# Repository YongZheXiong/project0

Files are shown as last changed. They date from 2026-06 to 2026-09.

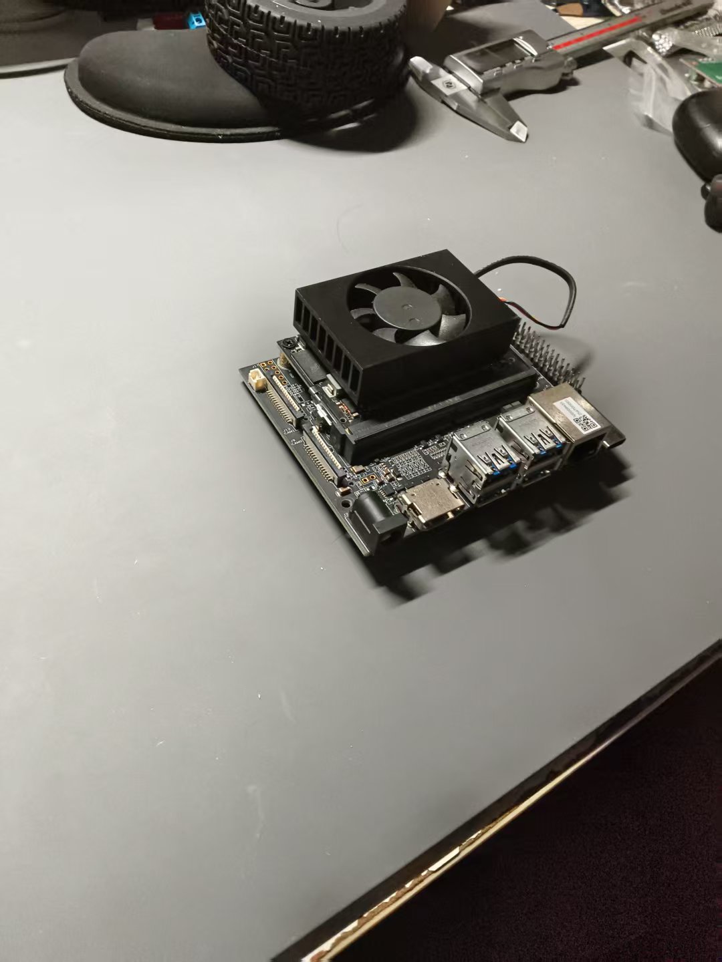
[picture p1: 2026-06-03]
hardware/reference_images/compute/EXIST-001_jetson_orin_nx_top_oblique.jpg

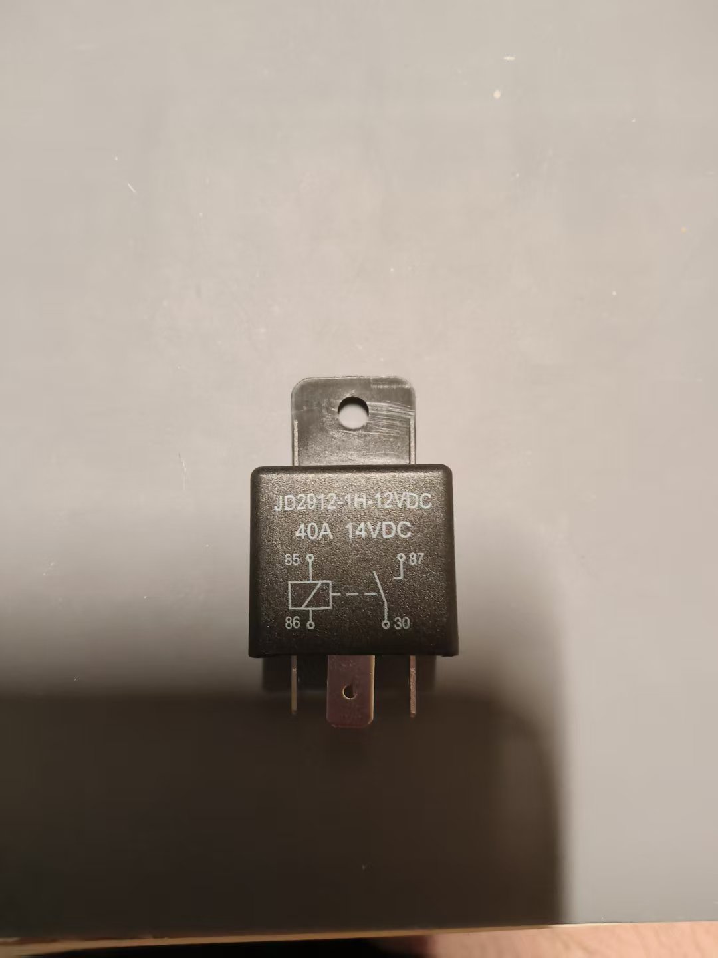
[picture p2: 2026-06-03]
hardware/reference_images/power/PWR-MOT-003_jd2912_relay_label_front_01.jpg

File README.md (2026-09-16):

# Project0

Project0 是一个面向室内走廊场景的四轮差速移动机器人项目，由个人完成机械、电气、底层控制、ROS2 软件与系统验收。项目以真机为主线，目标是形成可验证的感知—决策—执行闭环，依次完成基础运动、定位建图、导航和最小语义任务，并以完整项目报告收束成果。

## 项目目标

- 在固定室内走廊中建立可复现的单车系统基线。
- 让底盘、传感器、计算平台和 ROS2 软件形成真实闭环。
- 以分阶段验收记录机械、电气、通信、控制、感知和导航结果。
- 保留代码、配置、CAD、接线、测试与失败证据，支持复现和复盘。

## 当前进展

截至 2026-09-16，项目处于 H60 + MC520 底盘重建阶段。原 Orin NX/C1902 在一次电气异常后停止使用并送交专业维修；后续最终上位机可能为 Orin NX，也可能为 Orin Nano，型号尚未冻结。等待期间项目已推进 H60 能独立承接的四轮架空运动与断链安全子轨。

| 项目 | 当前状态 |
| --- | --- |
| 阶段与版本 | P2 / `v1.1-dev` / Unreleased；`v1.1.2` 已发布，冻结 H60-only 四轮架空与断链安全成果，P2 本身尚未完成 |
| 阶段门 | H0 已通过；H1/H2/H3/H5/H6 为 PARTIAL，H4 NOT RUN，H7 NOT PASSED，H8 NOT RUN；H1/H2 最终配置验收等待最终上位机到位 |
| 机械 | 28 个当前整车 STEP 已完成数字复审；H60 最终固定、线束应力释放与轮周净空已有用户报告受限证据，最终质量/重心、维护/风道和传感器视场回归等待最终上位机配置 |
| 固件 | 已同步 H60 默认安全固件、调度/诊断隔离、单通道表征、四轮固定 profile 和失联短租约回归；默认构建仍为 `MOTION=0 / CAL=0` |
| ROS2 | 已同步 H60 二进制协议桥、校准保持命令编码、手柄输入与安全仲裁的离线基线；Orin 不可用期间不声称完成 ROS2/实机联调 |
| 阶段性成果 | W2/M3 已取得 H60-only 受限通过：最终四路线束架空前进/后退/STOP，以及真实 USB-COM 断开后的定性四轮停车；不等于完整 H7/H8 |
| 历史平台 | STM32 + WSDC2412D + JGB37-520 + 三层底盘资料已归档 |

数字复审确认当前 CAD 的 28 个 STEP 均为有效 B-Rep，轴距为 `170 mm`、轮距约 `184.16 mm`，采用 6 根层间支柱，D435 水平安装。加工件到货后仍需按 H1 完成尺寸、孔位、平面度、连接器、风道、线束与维护空间的实物复核。

## 系统组成

| 子系统 | 当前方案 |
| --- | --- |
| 主计算 | Jetson Orin NX 或 Orin Nano，待最终确定；原 Orin NX/C1902 维修隔离 |
| 底层控制 | OpenCTR H60 V3.7 |
| 底盘 | 四轮差速，4 × MC520P56_12V，1:56，65 mm 橡胶轮 |
| 感知 | Livox Mid360 + Intel RealSense D435 |
| 供电 | 3S 电池 → 25A 主保险 → 主开关 → H60、Orin、Mid360 三条独立受保护支路 |
| 电压采样 | H60 `PC0` VIN ADC，多点校准后使用 |
| 通信目标 | Orin ↔ H60 版本化 UART 协议，带会话、序号、状态与故障语义 |

## 开发与验收

当前仓库提供 H60 架构、接线、默认运动锁定固件、受显式构建门保护的运动/诊断候选、二进制协议桥、CAD 和 H0-H8 验收基线。`v1.1.1` 冻结四轮单轮受限表征；`v1.1.2` 进一步公开 H60-only 四轮架空、断链停车和 localhost 安全控制核心。经完整 H5-H7 验收的动力运行固件仍在开发中。

Orin 维修期间的 H60-only 子轨不改变最终架构。既定手柄链是 USB 接收器接入 Orin 后经 ROS2/UART 下发；H60 是否能直接承接手柄输入仍为 `TBD / NOT RUN`，不会因临时目标调整而被写成已实现。

物理验证按以下顺序推进：

1. H0 到货与版本核对；
2. H1 不上电机械试装；
3. H2 断电电气检查；
4. H3 分支低能量上电；
5. H4 UART 单侧掉电与反向供电验证；
6. H5 固件故障注入；
7. H6 单通道电机与编码器；
8. H7 四轮架空与电源动态；
9. H8 受控场地落地低速。

当前停车与失能链由上电默认 `DISARMED`、显式 ARM、STOP/DISARM、通信超时、IWDG、异常撤 PWM、人工持续监护和主开关整车断电组成。车辆没有独立急停按钮、继电器或急停 GPIO；H8 仅在 H0-H7 全部通过、场地隔离、低速低加速度、主开关直接可达且操作者持续目视时执行。永久 UART 线束还需先完成任一侧掉电时的反向供电测量。

## 文档与资产入口

- [当前 H60 + MC520 实现基线](docs/02_architecture/p2_h60_rebuild_baseline.md)
- [无 Orin 本机网页控制覆盖层](docs/02_architecture/no_orin_web_teleop_architecture.md)
- [系统架构](docs/02_architecture/system_architecture.md)
- [电源、运动与采样边界](docs/02_architecture/h60_power_motion_sampling_boundary.md)
- [H60 电源接线](hardware/wiring/h60_power_wiring_v0_2.md)
- [H60 运动控制固件要求](firmware/h60_motion_control_firmware_requirements_v0_2.md)
- [H0-H8 重建验收计划](docs/06_testing/p2_h60_mc520_rebuild_acceptance_plan_2026-08-16.md)
- [当前公开 BOM](hardware/bom.md)
- [当前整车 CAD](hardware/cad/current_vehicle_v0_2/README.md)
- [重建基线报告](reports/h60_mc520_rebuild_baseline_2026-08-16.md)
- [v1.1.1 四轮单轮表征报告](reports/h60_four_wheel_characterization_v1_1_1.md)
- [v1.1.2 H60-only 四轮架空与断链报告](reports/h60_no_orin_w2_m3_v1_1_2.md)
- [无 Orin 本机安全控制台](tools/no_orin_web_teleop/README.md)
- [版本记录](CHANGELOG.md)
- [完整发布说明](docs/releases/README.md)

## 仓库结构

```text
Project0_public/
├── config/       # 配置入口
├── data/         # 数据索引与样例
├── docs/         # 架构、部署、标定与测试文档
├── firmware/     # H60 固件要求与上一平台实测记录
├── hardware/     # BOM、CAD、接线、参考资料与历史归档
├── reports/      # 系统与测试报告
├── scripts/      # 可复跑检查和测试工具
├── simulation/   # 仿真入口
├── src/          # ROS2 软件入口
├── tools/        # 离线控制、仿真与验证工具
└── presentation/ # 展示材料入口
```

## 历史资料

上一 STM32/JGB/WSDC 平台的 CAD、照片、接线和硬件台账保存在 `hardware/archive/`。历史文件中的完成状态仅对应其记录日期和当时平台；当前 H60 + MC520 新车以本 README、H60 架构文档和 H0-H8 验收计划为准。

## 版本、许可证与作者

- 当前开发版本：`v1.1-dev`；最新阶段性成果版本为 `v1.1.2`，下一候选为 `v1.1.3`。P2 完成并通过发布审查后才进入正式 `v1.1`。
- 最新阶段性成果：`v1.1.2`（2026-09-16），冻结 H60-only 四轮架空前进/后退/STOP、真实 USB-COM 断开后的定性停车证据和 localhost 安全控制核心；不表示 P2 或落地运动验收完成。
- 前一阶段性成果：`v1.1.1`（2026-09-08），冻结四轮单轮运动方向、编码器符号、工程 CPR 与受限停车证据。
- 最新历史开发预发布：`v1.1-dev.2`（2026-09-01）；它冻结 H0 基线与 H60 安全控制检查点，不表示 P2、基础运动或手柄控制已完成。
- 版本索引：[CHANGELOG.md](CHANGELOG.md)；完整说明：[docs/releases/README.md](docs/releases/README.md)
- 许可证：当前 [LICENSE](LICENSE) 为待确定占位，复用或分发前请先确认后续正式许可。
- 作者：Yongzhe Xiong

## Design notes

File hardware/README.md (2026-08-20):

# Project0 硬件目录

> 当前边界：当前方案是 H60 V3.7 + 4×MC520 的两层单车系统；只有 H60 `PC0` VIN 电压采样，没有独立急停按钮、继电器、急停 GPIO 或车载电流采样。
> 现场状态：采购、到货、装车、接线、上电、刷写和运动状态以对应验收记录及本轮现场确认为准。

## 当前活动入口

| 路径 | 作用 |
| --- | --- |
| `bom.md` | 当前整车主件、状态与验证入口 |
| `cad/current_vehicle_v0_2/` | 当前唯一活动 CAD 库，共 28 个 STEP |
| `wiring/h60_power_wiring_v0_2.md` | 当前唯一接线设计入口；尚未实装 |
| `reference_docs/` | 当前硬件原厂文档入口；尚缺 H60 / MC520 可归档的官方手册 |

## 历史归档

`archive/` 统一保留上一辆 STM32/JGB/WSDC 小车的 CAD、线束、电源调试、图片与 P1.3 盘点文档；WSDC 数据手册未包含在当前公开快照。归档中的急停、继电器、ACS712、STM32、WSDC、六路保险盒和三层车体只是历史事实，不得作为当前采购、接线、固件或验收输入。

## 当前维护规则

1. 当前硬件边界变化必须先形成可追溯依据，再同步 BOM、CAD、接线与验收计划。
2. 只有实物和原始证据可以把状态从“待采购/待确认”改为“已到货/已实装/已验证”。
3. 当前线径、端子、支路保护定值与 UART 反灌防护仍须在 H2–H4 根据实物冻结。
4. 当前 CAD 已通过数字结构检查，但不替代实物尺寸、公差、试装、强度、散热、线束可达性和维护性验收。

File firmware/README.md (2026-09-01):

# Firmware Workspace

本目录承接 Project0 当前 H60 固件需求，以及上一 STM32 平台的固件和实测历史。

当前入口包括 `h60_safe_control/` 与 `h60_motion_control_firmware_requirements_v0_2.md`。`h60_safe_control` 已提供并验证 `v0.1.1` 运动锁定固件：默认 `DISARMED`、显式 ARM 拒绝、协议边界、通信超时、IWDG 和异常撤 PWM；生产构建固定 `MOTION=0`，不配置 PWM，也不放行接电机或运动。反转斜坡、闭环和动力验收仍待实现。

以下 STM32 记录均为上一实车平台历史，不适用于 H60 引脚、协议、电机方向、编码器 CPR 或新平台验收：

上一 STM32 平台已有记录：

| 文件 | 作用 | 状态 |
|---|---|---|
| `stm32_safe_init_v0_1.md` | 记录 P2 电驱控制端安全初始化工程、GPIO 分配、编译/调试路径和实测结果 | 已完成阶段记录 |
| `stm32_lf_single_motor_pulse_test_v0_1.md` | 记录左前 `LF` 单电机低占空比短脉冲测试的临时固件行为、诊断过程和测试结果 | 已完成阶段记录 |
| `stm32_four_single_motor_pulse_tests_v0_1.md` | 记录 `LF / LR / RF / RR` 四个单电机低占空比短脉冲测试、右侧实物映射、主输入保险故障处理和测试后安全回烧 | 已完成阶段记录 |
| `stm32_suspended_linkage_pulse_tests_v0_1.md` | 记录悬空同侧双电机联动、四轮联动、右侧方向补偿、`LF` 起转门槛诊断和测试后安全回烧 | 已完成阶段记录 |
| `stm32_uart3_minimal_test_v0_1.md` | 记录 USART3 `PB10/PB11` 最小 UART 测试固件、双向 ACK、烧录和重启 / 冷启动复验 | 已完成阶段记录 |
| `stm32_encoder_acceptance_v0_1.md` | 记录旧平台新映射安全输出、四路编码器手动转轮、交叉测试、`LF` 故障定位和替换后复验 | 四路编码器低功率手动转轮通过 |

历史记录注意：

1. 旧 STM32CubeIDE 工程保留在非公开本地工作区，未纳入公开仓库源码管理；公开文档只保留可复核的历史结果摘要；
2. 仓库内 `stm32_safe_init_v0_1.md` 只记录该工程的事实、关键代码行为和验证结果；
3. `stm32_lf_single_motor_pulse_test_v0_1.md` 只记录一次左前单电机临时测试；
4. `stm32_four_single_motor_pulse_tests_v0_1.md` 记录四个单电机测试均已通过；`stm32_suspended_linkage_pulse_tests_v0_1.md` 继续记录悬空同侧联动、四轮联动和方向补偿结果；
5. 2026-06-22 的旧平台方向重映射作为历史结果保留；完整针序未在当前公开快照展开，不得迁移到 H60；
6. 当前悬空方向一致性已通过，但仅在悬空、短时、人工看守条件下成立，不表示整车落地运动已完成；
7. 原 STM32 在故障发生前最后一次已知烧录为安全初始化固件，现已因 3.3V 和 `RESET / NRST` 异常保持隔离；替换板已完成供电、烧录和 USART3 双向验收；
8. 2026-06-16 已补记 USB / 调试器反供电现象：主开关 OFF 但 STM32 USB 插着时，电驱端曾约 `4.16V`；拔掉 USB 后为 `0V`，不应仅凭电驱灯判断主动力状态；
9. `stm32_uart3_minimal_test_v0_1.md` 只用于 Orin X / Orin NX 与 STM32 UART 物理链路验证，烧录前第 4 路动力保险应保持拔出；
10. 2026-06-20 已完成替换板 USART3 最小双向 ACK、Orin 重启和 Orin / STM32 控制支路断电冷启动复验；正式控制协议当时仍未完成；
11. `stm32_safe_init_v0_1.md` 和既有短脉冲测试记录基于旧右侧引脚，只作为历史事实；改线后禁止直接使用旧固件恢复动力；
12. 2026-06-22 新映射固件已完成编译、烧录、安全输出、UART 和编码器读取测试；`LR / RF / RR` 编码器通过，`LF` 经交叉测试定位为电机内置编码器 / 内部连接器 / 原厂尾线侧故障；
13. 2026-07-13，`LF` 替换电机装车后重新压紧编码器蓝线 / 黑线并复验通过，四路编码器在第 4 路动力保险空置、人工手动转轮、UART 读数条件下均可产生有效计数；
14. 2026-07-13，旧 Windows STM32 工程已通过 U 盘取回，新 Mac 可构建当前 `project0_stm32_uart3_test`，车上 flash 已只读备份，active 固件前缀与旧 Windows 工程产物、新 Mac 构建产物一致；
15. 2026-07-14，`project0_stm32_uart3_test` 已加入阶段 D 前置控制层：新增 `STOP / SAFE / PULSE / DRIVE` 文本命令、`300ms` 通信超时停车、非法命令停车、`250ms` 短脉冲上限、`20 / 55` compare 上限和急停 `NO` 反馈状态；当日烧录 ELF SHA-256 为 `eb4d9c21ad2c4331132bc7258b529735dcae35e5e25987500af1212eea817ca5`；
16. 2026-07-14，用户确认第 4 路动力保险拔出后，阶段 D 前置控制固件已通过 OpenOCD 烧录到车上替换 STM32 并 `Verified OK`；Orin `/dev/ttyTHS1` 默认低功率 UART 复验 `overall=PASS`，未发送 `PULSE / DRIVE` 主动运动命令；当前观测到 `ESTOP=1`，需在阶段 D 前人工确认急停按钮状态和 `NO` 反馈转换；
17. 2026-07-17，急停按下 / 释放的 `ESTOP=1/0` 转换、急停动力切断、四路悬空前进 / 后退短脉冲和自动停车通过；诊断期间发现左后 `LR` 不动作，交叉测试证明电机与编码器正常，最终定位为 `set_left_forward()` 遗漏 `PD2 / PD3`；
18. 左后方向输出修复后的 ELF SHA-256 为 `583880a87b278a84922d24435b415d90d7ea15c16e880d584ec80ce4fb99e596`，OpenOCD `Verified OK`；动力保险拔出时正向输入实测 `INA2=0.17V`、`INB2≈3.3V`，恢复动力后的 `FWD / REV 12/55 200ms` 动作和编码器方向通过；
19. 2026-07-17，悬空 `LEFT / RIGHT 12/55 200ms`、单次 `DRIVE` 无新指令 `300ms` 超时和通信客户端中断后独立停车通过；形成原始编码器符号表，后续里程计应保留左侧符号并对右侧计数取反；
20. 阶段 D 悬空低层运动与安全停车验收完成；测试后急停按下、整车断电并拔出第 4 路动力保险。该结果不等同于里程计、ROS2 teleop、人工接管仲裁或阶段 E 落地运动通过。

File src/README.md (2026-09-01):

# ROS2 Source Workspace

`src/` 是 Project0 的 ROS2 Humble 源码包入口。当前已提供 H60 迁移的离线实现：

> `p0_base_bridge` 活动节点现使用 H60 版本化二进制协议、原始字节串口、STOP、新会话心跳、输入回中、显式 ARM、A-D 遥测和 ACK/NACK；`p0_safety_manager` 使用 `motion_ready` 和软件运动锁。默认配置保持 `motion_commands_enabled=false`、`wheel_mapping_confirmed=false`、`wheel_target_limit_mmps=0`，H60 `v0.1.1` 还固定报告运动输出不可用，所以本代码不能申请 ARM。旧 STM32 文本解析、16-bit 解绕、CPR 和 `ESTOP` 字段仅作历史兼容，不参与活动路径。本轮仅有 Mac 离线测试，不表示 Orin ROS2 构建、UART 实机、H4/H5、接电机或运动通过。

| 包 | 职责 | 当前边界 |
| --- | --- | --- |
| `p0_interfaces` | 底盘指令、H60 状态和运动锁服务 | `ChassisStatus` 已新增协议/固件版本、状态机、VIN、故障和 A-D 原始计数；旧 LF/RF 与 ESTOP 字段保持中性兼容 |
| `p0_base_bridge` | ROS2 到 H60 `/dev/ttyTHS1` 的二进制桥 | 离线实现已完成；A-D 映射、方向、CPR、轮径、Orin ROS2/H60 实机和单侧掉电反供电仍未验证，默认双门关闭 |
| `p0_safety_manager` | 通信/运动就绪、软件运动锁、手动/自动命令仲裁 | `/p0/motion/stop` 与 `/p0/motion/clear_lock` 已取代活动运行路径中的旧软件急停服务；清锁不自动 ARM |
| `p0_manual_control` | Flydigi Linux joystick 动态发现、无线心跳与 `sensor_msgs/Joy` 手动指令适配 | 真实映射和关机断开清零已无动力复验 |
| `p0_bringup` | 安全默认的组合启动和参数 | `base_control_no_motion.launch.py` 默认不产生活动运动指令 |

本机可运行不依赖 ROS2 的协议、串口、会话门控和仲裁单元测试。旧 STM32 平台的通信、计数解绕与 RR 失计只作为历史兼容背景，不是当前 H60 P2 阻塞。

`package.xml` 中的 `0.1.0` 是各 ROS2 包自身的历史包版本，不是 Project0 项目发布版本，不参与 P0–P10 的 `v0.1`–`v2.4` 映射。

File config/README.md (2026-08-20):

# 全局配置入口

## 目录用途

`config/` 用于登记跨多个软件包共享、需要在运行时统一选择的配置。当前只有本 README 是有意的：P2 的 H60 配置尚未实现和验收，因此不能为了让目录“看起来完整”而复制一份未经验证的 YAML。

H60 动力运行 YAML 尚未实现和验收。上一 STM32/JGB 小车的配置用于旧软件复现，不作为当前默认值。

## H60 配置建立条件

H60 迁移时，应先在 ROS2 bringup 包内形成可安装的真实运行配置，并完成：

1. 协议版本、设备路径和 UART 周期；
2. STOP/DISARM、显式 ARM、命令超时和故障行为；
3. 四路方向、计数边沿、CPR、轮径、轮距和速度/加速度限制；
4. H60 PC0 VIN ADC 多点校准版本；
5. 无动力、架空和落地对应验收。

只有出现两个或以上软件包确实需要共享同一配置，或者需要稳定的仓库级配置选择入口时，才在本目录增加文件。不得把同一 YAML 同时复制到两个位置手工维护。

## 更新机制

- 配置值的改变必须来自真实实现、标定或测试，不从 README 自动生成。
- 每次更新同时记录来源、单位、硬件/固件版本、适用模式、验证状态和回滚值。
- P2 的关键参数选择、证据和验证结果应随实现一并记录。
- 配置从“候选”变为“默认”前必须通过对应阶段门；未实测值不得写成冻结事实。
- 本 README 在目录职责、事实源位置或更新规则变化时人工受控更新，没有定时自动改写机制。

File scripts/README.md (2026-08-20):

# Utility Scripts

> 状态：通用 Orin 压力脚本可继续使用；所有 `stm32_*` 脚本均为上一平台历史工具，不支持 H60 协议、显式 ARM、状态机或故障字段，不得用于 H60 上电或运动准入。

## 测试脚本

| 脚本 | 说明 |
| --- | --- |
| `check_release_state.py` | 只读检查 README 当前阶段、开发版本、CHANGELOG 入口、阶段门、开发预发布与正式 Git 标签；在 P2 完成前阻止正式 `v1.1`，不自动提交、打标签或推送。 |
| `testing/orin_nx_mixed_stress_test.sh` | Orin NX CPU + GPU + 内存综合压力测试脚本，默认运行 20 分钟，带 `tj` 温度上限保护。 |
| `testing/orin_nx_gpu_stress.cu` | CUDA GPU 压力测试程序源码，由综合测试脚本编译和调用。 |

## 版本提醒

在每次恢复项目、阶段门变化和准备结束较大变更时运行：

```bash
python3 scripts/check_release_state.py
```

该脚本只做本地检查与提醒。正式发布仍需先完成阶段验收，再由用户批准提交、标签和推送；不采用“每天自动发布”。

阶段内已验证的任务可以形成普通开发提交；对外有价值的检查点可以发布递增的 `v1.1-dev.N` 开发预发布，并继续保留新的 `v1.1-dev / Unreleased` 入口。H0-H8 全部 `PASS` 时，脚本只把状态提升为“进入正式发布审查”；真实代码、通信/里程计/接管证据、阶段记录、CHANGELOG、发布 diff 和用户授权仍需人工复核。

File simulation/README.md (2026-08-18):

# Simulation Assets

当前没有可运行的 H60 + MC520 两层整车仿真模型、URDF/SDF、Gazebo world 或控制器接口。当前 STEP 是制造与数字审查输入，不等同于仿真资产；历史三层 CAD 也不得作为当前仿真入口。

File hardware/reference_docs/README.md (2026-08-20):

# 当前硬件原厂文档

本目录是当前 H60 / MC520 方案的原厂手册与可归档数据手册入口。目前只有说明文件，还没有已归档的 H60 / MC520 官方 PDF；不得凭商品页摘要补写引脚、电气限值或保护参数。

上一 WSDC2412D 电驱 PDF 未包含在当前公开快照，只作历史证据。原厂文档中可复用的结论必须再写入当前 BOM、接线基线或验收记录，不能只停留在原始文档中。

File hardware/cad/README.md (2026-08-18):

# Project0 CAD 资料

## 当前活动资产

`current_vehicle_v0_2/` 是 H60 + MC520 两层整车的当前公开 CAD 入口：

- 28 个原始 STEP：`current_vehicle_v0_2/step/`
- 文件清单与验证边界：`current_vehicle_v0_2/README.md`
- SHA-256：`current_vehicle_v0_2/MANIFEST.sha256`

上一平台的三层底盘、STM32/JGB37 轮系和电源托盘已移至 [`../archive/cad_legacy_pre_h60_2026-08-18/`](../archive/cad_legacy_pre_h60_2026-08-18/)，不再出现在活动 CAD 目录，也不得用于当前加工、装配或仿真输入。

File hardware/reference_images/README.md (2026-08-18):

# Hardware Reference Images

本目录存放 Project0 硬件实物图片、接口近景、安装参考图和底盘布局试摆图片。

图片用于辅助理解硬件外形、接口朝向、线束空间和安装关系，不替代 BOM、datasheet、实测尺寸或 CAD 设计输入。

## 目录说明

| 目录 | 放置内容 |
|---|---|
| `power/` | 主电池、主开关、保险座、保险盒、继电器、急停按钮、DC-DC、电源分配相关图片 |
| `compute/` | Orin NX、SSD、计算平台接口、散热和固定方式相关图片 |
| `control/` | 上一平台 STM32、电压采样、电流传感器等控制模块历史图片 |
| `sensing/` | Mid360、D435、传感器支架、传感器线缆相关图片 |
| `drive/` | 电机、电机驱动板、轮胎、联轴器、电机支架相关图片 |
| `wiring/` | 线材、端子、接插件、热缩管、线束固定件、标签相关图片 |
| `mechanical/` | 底盘板、立柱、螺丝、垫片、安装座、3D 打印件相关图片 |
| `layout/` | 多个硬件一起试摆、底盘总体布局、装车参考图、草图 |

## 命名建议

建议文件名包含 BOM `item_id`、硬件名称、视角和日期。

示例：

```text
PWR-001_main_battery_top_2026-05-26.jpg
PWR-MOT-004_motor_driver_connector_side_2026-05-26.jpg
LAYOUT_chassis_layer1_trial_layout_2026-05-26.jpg
```

## 使用规则

公开图片不得保留设备序列号、可扫描二维码、账号、订单、地址或其他可关联个人/机构的信息；必要时先脱敏，无法可靠脱敏则不纳入当前公开快照。

1. 单个硬件图片放入对应模块目录。
2. 多个硬件一起摆放、用于判断底盘布局的图片放入 `layout/`。
3. 涉及安装孔、接口、线缆出口或高度判断的图片，尽量带尺子、卡尺或螺丝作为尺度参考。
4. 关键尺寸仍应记录到 BOM 或对应 CAD 设计输入文件中，不能只依赖图片判断。

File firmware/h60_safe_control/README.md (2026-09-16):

# H60 safe-control firmware

本目录保存 Project0 面向 OpenCTR H60 V3.7 / STM32F407VET6 的安全控制固件、默认关闭的运动候选以及宿主测试。

## 默认安全边界

默认 `make firmware` 构建保持：

- `MOTION=0 / CAL=0`，上电默认 `DISARMED`；
- 八路 H 桥输入先锁为 GPIO 低电平；
- ARM 在运动条件未满足时返回 `MOTION_LOCKED`；
- STOP、DISARM、通信超时、协议错误、断言、HardFault 与 IWDG 路径统一撤销输出；
- 运动审计、单通道表征、四轮固定 profile 和复位诊断均使用独立编译门，不能泄漏到默认制品。

## 隔离构建

| 入口 | 作用 | 关键限制 |
| --- | --- | --- |
| `make motion-audit-firmware` | 编译运动控制路径供离线审计 | `CAL=0`，仍不能 ARM |
| `make m2a-verify` | 单通道短租约校准候选 | 每次 ARM 仅一通道/方向，75 ms 非零租约 |
| `make h6-characterization-firmware` | H6 单通道固定档位表征候选 | 默认关闭，不是生产参数 |
| `make w2-four-wheel-profile-firmware` | 四轮固定 80‰ 前/后 profile | 每次 ARM 固定方向，换向必须 STOP 后重新 ARM |
| `make w2-five-second-link-loss-firmware` | 五秒绝对 ARM 上限候选 | 仍保留 75 ms 命令租约；仅用于断链验证 |
| `make iwdg-diagnostic-firmware` | IWDG/HardFault 复位诊断 | 强制 `MOTION=0`，与运动构建互斥 |

这些入口只生成可审计制品，不构成刷写、接电机或运动授权。

## 验证

```bash
make test
make sanitize
make source-safety-test
make motion-lock-test
make firmware
make verify
make w2-four-wheel-profile-test
make w2-five-second-link-loss-test
```

测试覆盖状态机、协议、调度周期、输出提交前中断、超时/STOP 清零、IWDG 诊断隔离、非法编译组合拒绝和 ARM 构建检查。ARM 交叉编译需要 GNU Arm Embedded 工具链；宿主测试使用系统 C 编译器与 Python 3。

## 当前证据边界

- 四轮最终线束架空前进、后退和 STOP 已形成 H60-only 受限证据。
- 真实 USB-COM 断开后的四轮停车有数字记录和双机视频支持，但没有视频—串口独立时钟校准，不能宣称精确停轮时间。
- 当前结果不覆盖上位机链路、单侧掉电反供电、带载、落地、低电量、热、长时、电流/PWM 波形或完整 H6-H8。
- 最终生产参数与完整 P2 资格仍由后续验收决定。

公开摘要见 [`../../reports/h60_no_orin_w2_m3_v1_1_2.md`](../../reports/h60_no_orin_w2_m3_v1_1_2.md)。

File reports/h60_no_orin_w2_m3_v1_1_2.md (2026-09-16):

# H60-only 四轮架空与断链停车受限成果报告（v1.1.2）

## 目的与范围

本报告汇总最终上位机不可用期间，Project0 由本机网页后端直接监督 H60 所取得的 W2/M3 受限成果。测试均为四轮可靠架空、短时、固定 profile；没有执行落地运动。

## 架空前进、后退与 STOP

- 当前 H60 固件和最终四路线束完成一次前进、一次重新 ARM 后的后退；
- 两段各取得 13 条有效四轮 profile；
- 后端分别在约 `304 ms`、`307 ms` 取得 STOP ACK；
- 四路编码器在两个方向均有增量且符号反转；
- 原始数据重解析得到 2234 个完整包、2197 帧连续遥测，解析错误和故障均为 0；
- 操作者确认四轮方向一致、全部停轮且未见异常，最终状态为 `DISARMED`。

该结果支持 `W2_AIRBORNE_FORWARD_REVERSE_STOP = PASS_LIMITED_H60_ONLY`。

## 真实链路断开

- 固定 `80‰` 四轮前进 profile 共 21 条获得 ACK；
- 断链前四路有符号编码器增量约为 `[+204, -213, +168, -175]`；
- 目标 USB-COM 随后消失，主机的尽力 STOP 没有 ACK；
- 操作者记录四轮断链后全部停止且没有重新启动；
- 两个相对机位的视频副本分别覆盖左右两侧轮组，音轨相关支持它们来自同一次连续事件；逐帧可见四轮先转、随后停止，剩余录像无重启。

结合架空前/后退与 STOP 结果，当前结论为：

`W2_PASS_LIMITED_H60_ONLY / M3_PASS_LIMITED_H60_ONLY`

## 可复用工程结论

- localhost 后端、短租约与 H60 本地失效保护可以组成受限的临时控制链；
- 客户端断开、旧请求、方向切换和 STOP 未确认必须由后端 fail-closed；
- H60 的 75 ms 非零命令租约与独立 ARM 绝对上限应保持分层，不以主机窗口替代板端保护；
- 上位机恢复后可复用同一意图/租约/故障语义，但仍需重新验证真实 UART 与系统恢复。

## 已知限制

- 视频是传输后的副本，不是已核验的相机母文件；拔线动作未进入画面；
- 视频时钟未与串口时钟独立校准，不能据此宣称 75 ms 或其他精确 PWM/停轮时间；
- 没有覆盖上位机链路、重连拒旧请求的整车实测、VIN 动态、电流、定量温升、带载、低电量、长时或落地运动；
- H6、H7、H8 和 P2 均未完整通过；本成果不构成整车运动准入。

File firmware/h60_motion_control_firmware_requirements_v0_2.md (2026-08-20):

# H60 运动控制固件要求 v0.2

> 状态：正式需求 / 尚未实现
> 依据：当前 H60 + MC520 数字基线与公开验收门
> 目标：定义 H60 获得动力测试准入前的最小可验证固件行为

## 1. 状态机

最小状态为 `BOOT -> DISARMED -> ARMED -> FAULT`。

1. 上电、复位、棕断恢复和看门狗复位后必须进入 `DISARMED`，四路 PWM 为 0。
2. `DISARMED` 清除上一会话的速度目标、PID 状态、方向切换状态和命令序号。
3. 只有自检、通信心跳、故障状态和命令新鲜度通过，并收到新会话显式 ARM，才能进入 `ARMED`。
4. ARM 前速度目标必须为零，人工操纵输入必须回中；保持的摇杆或缓存 `cmd_vel` 不得通过。
5. STOP、DISARM、通信超时、非法帧、序号回退、看门狗前置、异常入口和本地故障必须先撤销四路 PWM，再清控制状态。
6. H60 或 Orin 重启、UART 断开与恢复都不得自动恢复 `ARMED`。

## 2. 通信协议

协议至少包含：

- 固定帧头、协议版本、显式长度和最大长度；
- 会话 ID、单调序号和 CRC；
- ARM、DISARM、STOP 和速度命令；
- 心跳与短命令超时；
- 四轮原始计数、速度、故障、VIN、固件版本和状态机状态；
- 对越界长度、未知命令、重复/过期序号和 CRC 错误的失效导向处理。

控制命令超时可从 `200–300 ms` 台架起步，最终值必须结合 ROS2 调度、UART 周期和停车实测冻结。记录选择时要列出候选值、风险和测试结果。

## 3. 电机控制

1. 四路 MC520P56 独立采集 AB 编码器，计数边沿、CPR、减速比和 A/B 方向必须可配置并实测标定。
2. 速度闭环应包含输出限幅、加减速斜坡、积分抗饱和和反转零输出保持。
3. 禁止从正向 PWM 直接跳到反向 PWM；必须先减到零并满足最小死区。
4. 当前没有电流采样，也没有基于电流遥测的软件堵转保护；堵转风险由驱动限制、保守命令和受监督台架测试约束。
5. H60 `PC0` VIN ADC 必须多点校准，并上报原始值、换算值和校准版本；电压采样不替代 BMS 或保险。

## 4. 异常与看门狗

1. 启用 IWDG；所有异常处理入口必须先将电机 PWM 置零。
2. HardFault、MemManage、BusFault、UsageFault、断言失败和不可恢复协议错误不得在保留旧 PWM 的死循环中停留。
3. 在不延迟撤 PWM 的前提下记录故障与复位原因。
4. UART 和缓冲区访问先检查长度与索引，不信任上位机输入。
5. 默认参数、校准缺失、版本不兼容或关键自检失败时保持 `DISARMED`。

## 5. 验收门

- 可复现构建，固件版本、工具链与散列可记录；
- 上电和复位重复测试不出现非零 PWM；
- UART 断开、停止发送、乱码、CRC 错、过长帧和 Orin 重启均自动停车；
- 看门狗与故障注入先撤 PWM；
- 四轮架空方向、超时、斜坡和反转通过；
- VIN ADC 多点校准误差有记录；
- 只有电源、反供电、温升、结构和前置测试门同时通过，且用户明确授权，才进入落地低速测试。

## 6. 记录要求

每次参数或方案选择都应随实现记录选择理由、真实源码、构建输出、测试结果和证据路径。失败和未完成项同样记录。

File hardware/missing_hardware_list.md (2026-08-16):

# Project0 缺失硬件清单

> **历史清单**：本文是上一 STM32/JGB/三层平台的缺失项收束记录，不再用于 H60 重建采购判断。当前目标配置见 [bom.md](bom.md)，到货与缺口在 H0 重新确认。

> 文档状态：P1.3 缺失硬件收束台账 / 到货验收待闭环
> 适用阶段：P1.3 硬件方案与采购收束；P2 装配前置承接
> 依据范围：已有硬件清单、硬件架构基线、电源架构边界、人工接管决策、急停决策、底盘结构决策、传感器安装策略决策。
> 文档目的：按整车硬件拓扑结构，列出当前相对于迭代一硬件基线仍缺失或需装配验证的公开硬件条目，用于和 `hardware/bom.md` 共同说明当前硬件准备状态。采购链接、价格、供应商和内部采购过程不在公开仓库展开。
---

## 0. 编写边界

1. 本清单只列出当前 P1.3 硬件方案与采购前置所需的缺失硬件，不展开 P2-P6 实现细节，也不纳入 P7-P10 迭代二增强硬件。
2. 当前公开状态为 P1.3 核心采购已收束，剩余到货验收与 P2 装配前置仍需继续承接。
3. 本清单不修改 DEC，不改变 Architecture 技术事实，不替代正式 BOM 或最终采购决策。
4. 当前硬件命名基线采用：Jetson Orin NX 16GB、Livox Mid360、Intel RealSense D435、JGB-520、飞智黑武士2手柄 + 2.4G USB 接收器。
5. 对于架构已确认“需要存在”但具体型号尚未确认的器件，本文使用“具体硬件名称 + 型号待定”的方式记录，不虚构未确认型号；当前线材、线径和 UART 端子采购口径已由 `hardware/wiring/wire_selection_v0_1.md` 初步收束，但正式接线图、端子压接、通断、极性和温升验证仍待 P2 装配阶段完成。补光模块按 既有设计记录 暂缓采购，保留后续恢复选型可能。
6. 三层底盘结构已由 既有设计记录 与公开 CAD 资料承接；第一层、第二层、第三层底板已外发加工，本文后续机械条目按“待到货验收 / 待实物装配复核”口径记录。
7. Orin NX 载板替换已确认最终购买 C1902 V1.1 载板；当前状态为已购买、未到货、待验证，散热能力、外接 RTC 电池、40W / MAXN SUPER 稳定性和装车适配仍待确认。

---

## 1. 已有硬件基线

以下硬件已在现有硬件清单中出现，因此不列入缺失硬件：

| 拓扑位置 | 已有硬件 | 数量/状态 | 说明 |
|---|---:|---:|---|
| 计算平台 | SEEED STUDIO Jetson Orin NX 16GB 官方套件 | 1 | 含 Jetson Orin NX 16GB、J401 载板、散热风扇、512GB SSD，供电电压范围为 9–19V。|
| 主激光雷达 | Livox Mid360 | 1 | 当前用途为主激光雷达，命名统一为 Mid360。 |
| Mid360 线缆 | Livox Mid360 一分三线 | 1 | 一端为 12 芯 M12 航空插头母头，另一端包含电源线、以太网线和功能线。 |
| 前向视觉/深度传感器 | Intel RealSense D435 | 1 | 当前角色为前向辅助深度/视觉传感器，接口为 USB 3.0 Type-C。 |
| D435 数据线 | Intel RealSense D435 USB 3.0 Type-C 数据线 | 1 | 已确认存在，可直接连接 D435 与 Orin NX。 |
| 运动部件 | 轮胎 | 2 | 现有轮胎数量为 2，而迭代一底盘采用四轮驱动差速式平台，因此仍需补足轮胎数量。|
| 人工接管输入设备 | 飞智黑武士2手柄 + 2.4G USB 接收器 | 1 套 | 已确认存在，人工接管链路可直接使用。 |
| 线材 | 22AWG 耐高温硅胶线 | 5 卷 / 共 100 米 | 已有颜色包括白、棕、灰、紫、橙。 |
| 线材 | 1007 / 22AWG 电子线 | 已有 | 已有颜色包括橙、白、紫、灰、棕。 |
| 辅料 | 热缩管 | 已有，规格待补充 | 已列入现有物料，但规格仍待补充。 |
| 工具 | 安立信 T12 电烙铁 | 1 | 已有调试/焊接工具。|
| 工具 | 正点原子 DS100 手持数字示波器 | 1 | 已有调试工具。 |
| 工具 | 德力西万用表 | 1 | 已有调试工具。 |

---

## 2. 缺失硬件清单总览

> 拓扑顺序：  
> 主电源入口层 → 动力支路层 → 计算支路层 → 传感器/控制支路层 → 感知安装层 → 人工接管输入层 → 底盘机械结构层 → 线束与固定辅件层。

---

## 3. 主电源入口层

整车采用单主电池统一供能，电源分为动力支路、计算支路、传感器/控制支路和 Mid360 独立 12V 感知供电支路。

| 编号 | 缺失硬件 | 数量 | 所属拓扑节点 | 用途 | 缺失依据 | 规格/型号状态 |
|---:|---|---:|---|---|---|---|
| PWR-001 | 3S 主电池 | 1 | 主电池统一能源入口 | 为整车提供统一能源输入。 | 电源架构确认主电池作为统一能源入口，动力支路采用 3S 电池直供电机驱动板；现有硬件清单未列出主电池。 | 已按 既有设计记录 确认并采购定制 3S 主电池；已到货待验证，仍需型号、参数、接口、外观和 P2 上电前验证。 |
| PWR-002 | 主电池电源连接器组件 | 1 套 | 主电池 → 主电源入口 | 连接主电池与整车主供电回路。 | 电源架构要求主电池统一供能，后续接线图需体现不同支路分区；现有硬件清单未列出主电池连接器。 | 已按 既有设计记录 确认为 XT60 公头自制主电池入口连接组件；已到货待验证，后续需型号、参数、接口、外观和 P2 上电前验证。 |
| PWR-006 | 主输入保险座 / 保险丝 | 4 套 | 主电池正极输出 → 主电源总开关 | 作为整车总输入主保险，首版装车使用 1 套。 | 既有设计记录 确认主输入保护采用 ATO / ATC 保险座 + 25A 插片保险丝，并尽量靠近电池正极输出。 | 已到货待验证；后续需确认保险丝规格、保险座线径、触点可靠性和 P2 上电前电气安全。 |
| PWR-003 | 主电源总开关 | 1 | 主电源入口 | 用于整车主电源上电/断电控制。 | P1 电源架构要求电源路径与保护边界清晰，主电池作为统一能源入口需要主入口控制器件；现有硬件清单未列出总开关。| 已按 既有设计记录 确认为汽车 / 摩托车电瓶断电旋钮开关；已到货待验证，后续需型号、参数、接口、外观和 P2 上电前验证。 |
| PWR-004 | 主电池托盘 | 1 | 主电池机械固定 | 对主电池进行下层中部偏后位置的托盘式限位。 | 既有设计记录 确认主电池安装在下层中部偏后位置，并采用托盘式限位结构；采购中需补充托盘材料。| 已采购待到货；材料和尺寸待实物确认，公开仓库不展开采购链接、价格和供应商。 |
| PWR-005 | 主电池固定绑带 | 2 | 主电池机械固定 | 配合托盘限制电池上下跳动和振动脱落。 | 既有设计记录 确认主电池采用托盘式限位结构并配合绑带辅助固定；现有硬件清单未列出绑带。 | 已采购待到货；宽度和长度待实物确认，公开仓库不展开采购链接、价格和供应商。 |

---

## 4. 动力支路层

动力支路从主电池进入硬件急停链路，再给两块双路电机驱动板供电，两块双路电机驱动板驱动四个电机。

| 编号 | 缺失硬件 | 数量 | 所属拓扑节点 | 用途 | 缺失依据 | 规格/型号状态 |
|---:|---|---:|---|---|---|---|
| PWR-MOT-001 | 蘑菇头急停按钮 | 1 | 主电池/动力支路 → 硬件急停 | 作为纯硬件急停输入，直接切断动力支路。 | 既有设计记录 确认急停按钮安装在车体顶部中后部，通过纯硬件链路切断电机驱动供电，不经过软件链路；现有硬件清单未列出急停按钮。 | 已按 既有设计记录 确认为工业面板式红色 40mm 蘑菇头急停按钮，1NO + 1NC，自锁复位，不带灯；已到货待验证。 |
| PWR-MOT-003 | 急停动力切断执行器件 | 1 | 硬件急停 → 动力支路切断 | 执行急停后的动力支路断电。 | 硬件架构明确急停边界为只切动力支路，不切断计算、控制、感知和记录支路；既有设计记录 已确认采用汽车继电器作为首版执行器件。 | 已按 既有设计记录 确认为 JD2912 12V 40A 四脚汽车继电器，带线座；已到货待验证。 |
| PWR-MOT-004 | 双路电机驱动板 | 2 | 动力支路 → 电机驱动 | 两块双路驱动板覆盖四个电机驱动需求。 | 既有设计记录 确认采用两块双路电机驱动板，驱动板安装在下层动力区；现有硬件清单未列出电机驱动板。 | 已按 既有设计记录 确认为 WAYNESTARK WSDC2412D-V3.0；已到货待验证。 |
| PWR-MOT-005 | JGB-520 带编码器减速电机 | 4 | 电机驱动板 → 四轮驱动执行 | 构成四轮驱动差速式底盘的四个执行电机，并向 STM32 提供编码器反馈。 | 既有设计记录 确认迭代一底盘采用四轮驱动差速式地面移动平台，硬件架构确认两块双路电驱板驱动四个电机，四个电机编码器反馈进入 STM32；现有硬件清单未列出电机。| 已采购新永泰电机 JGB37-520-12100，命名基线仍统一为 JGB-520；已到货待验证，后续需实物确认。 |
| PWR-MOT-006 | 轮胎 | 2 | 四轮驱动底盘 | 补足四轮底盘所需轮胎数量。 | 现有硬件清单只有轮胎 ×2，而 既有设计记录 确认底盘采用四轮驱动结构。| 已采购并已到货待验证；尽量与已有轮胎规格一致。 |
| PWR-MOT-007 | 轮毂联轴器 / 电机轮连接件 | 4 | 电机输出轴 → 轮胎 | 连接 JGB-520 电机输出轴与轮胎。 | 现有轮胎说明中连接方式为“联轴器连接电机输出轴”，但已有硬件清单未列出联轴器本体。 | 已采购并已到货待验证；需匹配电机输出轴与轮毂。 |
| PWR-MOT-008 | 电机安装座 / 电机固定支架 | 4 | 第一层底板 → 电机 | 将四个电机固定到底盘结构上。 | P2 阶段需要完成底盘机械组装、电机安装和轮子安装；公开硬件台账记录该支架已随新永泰电机到货。 | 已到货待验证，尺寸需匹配 JGB-520 与第一层底板。 |

---

## 5. 计算支路层

Orin NX 是主计算平台，使用独立高优先级稳压供电支路，并与动力支路电气隔离。

| 编号 | 缺失硬件 | 数量 | 所属拓扑节点 | 用途 | 缺失依据 | 规格/型号状态 |
|---:|---|---:|---|---|---|---|
| COMP-001 | Orin NX 独立 DC-DC 稳压电源模块 | 1 | 主电池 → 计算支路 → Orin NX | 为 Orin NX 提供稳定供电。 | 既有设计记录 确认 Orin NX 使用独立高优先级稳压供电支路，与动力支路电气隔离；现有硬件清单未列出 DC-DC 稳压模块。| 已按 既有设计记录 确认为 IIO-PW936 1-4，9V-36V 输入，12V 输出，13A / 120W，非隔离；已到货待验证。 |
| COMP-002 | Orin NX 安装板 / 固定支架组件 | 1 套 | 上层计算控制区 | 固定 Jetson Orin NX 16GB 官方套件。 | 硬件架构待细化项包含 Orin NX 与 STM32 固定孔位；现有硬件清单只列出 Orin NX 套件，未列出安装结构件。 | 已采购待到货；孔位、高度、绝缘、散热避让和维护可达性待 P2 装配确认。 |
| COMP-003 | Orin NX UART 转接/连接线组件 | 1 套 | Orin NX ↔ STM32 UART | 实现 Orin NX 与 STM32 的 UART 双向通信物理连接。 | 既有设计记录 确认 Orin NX 与 STM32 通过 UART 双向通信，Orin NX 下发速度指令，STM32 上传编码器、底盘状态和异常状态。 | 由 WIRE-004 三芯屏蔽线 + 2.54mm 杜邦母头端子 + 3P 胶壳承接；本轮不单独采购额外 UART 转接件，P2 实物确认后再判断是否补件。 |
| COMP-004 | Orin NX C1902 V1.1 载板 | 1 | Jetson Orin NX 16GB 核心模组 → 主计算平台载板 | 替换当前 J401 载板，释放更高功耗 / 更高推理性能使用空间，并降低后续结构返工风险。 | 已确认最终购买 C1902 V1.1 Orin Nano / NX 系列载板。 | 已购买待到货；散热能力、外接 RTC 电池、孔位、DC5525 防松、USB 供电余量和 40W / MAXN SUPER 稳定性待到货后验证。 |

---

## 6. 传感器/控制支路层

传感器/控制支路为 STM32、状态采样、状态输入等低压控制类硬件提供供电和接口支撑；补光控制当前按 既有设计记录 暂缓，仅保留后续小信号扩展可能。

| 编号 | 缺失硬件 | 数量 | 所属拓扑节点 | 用途 | 缺失依据 | 规格/型号状态 |
|---:|---|---:|---|---|---|---|
| CTRL-001 | 传感器/控制支路 DC-DC 电源模块 | 1 | 主电池 → 传感器/控制支路 | 为 STM32、采样模块、状态输入等低压控制硬件供电；补光控制仅保留后续扩展可能。 | 既有设计记录 确认低压侧至少划分为计算支路和传感器/控制支路；现有硬件清单未列出该支路 DC-DC 模块；既有设计记录 已确认具体选型。 | 已按 既有设计记录 确认为 5V / 6A DC-DC Buck 降压稳压模块，7V-38V 输入，5V 固定输出，长期输出 <=5A；已到货待验证。 |
| CTRL-002 | STM32 控制板 | 1 | 底层控制平台 | 负责电机控制、编码器读取、电压/电流采样、UART 通信和底层保护。 | 硬件架构确认主计算平台为 Orin NX，底层控制平台为 STM32，且 STM32 与 Orin NX 通过 UART 双向通信；现有硬件清单未列出 STM32 控制板。 | 已按 既有设计记录 确认为 STM32F407VET6 核心板 / 开发板 V5.5；已到货待验证。 |
| CTRL-003 | STM32 安装支架 / 固定柱组件 | 1 套 | 上层计算控制区 | 固定 STM32 控制板。 | 硬件架构待细化项包含 Orin NX 与 STM32 固定孔位；现有硬件清单未列出 STM32 固定结构件。 | 孔位与高度待装配设计确定。 |
| CTRL-004 | 主电池电压采样模块 | 1 | 主电池 → STM32 状态采集 | 将主电池电压状态纳入系统管理输入。 | 既有设计记录 确认迭代一正式实现基础电量监测上报，主电池电压状态纳入系统管理输入；硬件架构确认主电池电压检测进入 STM32。 | 已按 既有设计记录 确认为 Keyes 电压检测模块，0-25V 输入，5 倍分压，模拟输出；已到货待验证。 |
| CTRL-005 | 动力支路电流检测模块 | 1 | 动力支路 → STM32 状态采集 | 采集动力支路电流状态，用于底层状态与系统管理。 | 硬件架构确认主电池电压检测和动力支路电流检测进入 STM32；既有设计记录 已确认首版采用 ACS712-30A 模拟电流检测模块。 | 已按 既有设计记录 确认为 ACS712-30A 电流传感器模块 / ACS712ELC-30A，5V 供电，30A 量程，模拟输出；已到货待验证。 |

---

## 7. 感知安装层

Mid360 接入 Orin NX 并作为迭代一主定位建图链路输入，D435 接入 Orin NX 用于前向辅助视觉/深度感知、调试和数据记录。补光模块按 既有设计记录 暂缓采购，当前只保留接口和安装空间可能。

| 编号 | 缺失硬件 | 数量 | 所属拓扑节点 | 用途 | 缺失依据 | 规格/型号状态 |
|---:|---|---:|---|---|---|---|
| SENS-001 | Mid360 顶部安装支架 | 1 | 顶部感知层 → Mid360 | 将 Mid360 安装在车体顶部，尽量接近几何中心。 | 既有设计记录 确认 Mid360 安装在车体顶部并尽量接近几何中心；公开 CAD 资料已归档 Mid360 平台 CAD。 | 已建模待加工 / 待实物装配验证。 |
| SENS-002 | Mid360 增高立柱 / 支撑柱组件 | 1 套 | 顶部感知层 → Mid360 | 使 Mid360 明显高于上层板，优先保证视场。 | 既有设计记录 确认 Mid360 支架允许明显高于上层板；公开 CAD 资料已归档 Mid360 平台支柱 CAD。 | 已建模待加工 / 待实物装配验证。 |
| SENS-003 | D435 前向安装支架 | 1 | 车头前向感知位 → D435 | 将 D435 固定在车头前向区域。 | 既有设计记录 确认 D435 安装在车头前向区域；公开 CAD 资料已归档 D435 固定 5 度支架 CAD。 | 已建模待加工 / 待实物装配验证。 |
| SENS-004 | 补光模块 | 1 | D435 附近 → 弱光视觉支撑 | 暂缓采购；保留后续根据暗光测试恢复选型可能。 | 既有设计记录 确认当前可选补光模块体积偏大，且实验环境通常存在基础可见光，因此不进入当前 P1.3 采购批次。 | 暂缓。 |
| SENS-005 | 补光控制模块 | 1 | Orin NX / STM32 控制意图 → 补光模块 | 暂缓采购；随补光模块后续恢复选型。 | 既有设计记录 确认补光模块暂缓采购；控制模块不单独采购。 | 暂缓。 |
| SENS-006 | 补光模块安装支架 | 1 | D435 附近 → 补光模块 | 暂缓采购；后续若恢复补光模块选型，再按灯体尺寸确定结构。 | 既有设计记录 确认补光模块暂缓采购；安装支架不单独采购。 | 暂缓。 |
| SENS-009 | Mid360 独立 12V DC-DC 稳压模块 | 1 | WIRE-001 分路保险盒 → Mid360 | 为 Mid360 提供独立 12V 稳压供电。 | 既有设计记录 确认 Mid360 不直接裸接主电池、不共用 Orin NX 计算支路 DC-DC、不挂载到 CTRL-001 传感器/控制支路 DC-DC，而是采用独立 12V DC-DC。 | 已按 既有设计记录 确认为 UENPO / 恩珀科技 S3 阻燃中塑胶壳 DC-DC 电源模块，10-36V 输入，12V 输出，3A / 36W，非隔离，IP68；已到货待验证。 |

---

## 8. 人工接管输入层

人工接管硬件链路为：飞智黑武士2手柄 → 2.4G USB 接收器 → Orin NX → teleop / 手动控制节点 → cmd_vel → 底盘桥接 → UART → STM32 → 电驱板 → 电机。

| 编号 | 缺失硬件 | 数量 | 所属拓扑节点 | 用途 | 缺失依据 | 规格/型号状态 |
|---:|---|---:|---|---|---|---|
---

## 9. 底盘机械结构层

整车采用四轮驱动差速式地面移动平台，当前车体结构已由 既有设计记录 与公开 CAD 资料收束为三层底盘冻结结构，三层底板之间采用立柱 / 支撑柱连接。

| 编号 | 缺失硬件 | 数量 | 所属拓扑节点 | 用途 | 缺失依据 | 规格/型号状态 |
|---:|---|---:|---|---|---|---|
| MECH-001 | 第一层底板 | 1 | 底层动力与主电源 | 承载底层动力、主电源、轮系、电源托盘和下层线束空间。 | 既有设计记录 确认三层底盘冻结结构；公开 CAD 资料已归档第一层底板 CAD。 | 已外发加工，待到货验收。 |
| MECH-002 | 第二层底板 | 1 | 中层控制 / 电源分配 / 线束过渡 | 承载中层控制、电源分配、部分电源/控制模块和线束过渡。 | 既有设计记录 确认三层底盘冻结结构；公开 CAD 资料已归档第二层底板 CAD。 | 已外发加工，待到货验收。 |
| MECH-003 | 第三层底板 | 1 | 上层计算 / 感知安装 / 调试维护 | 承载上层计算、感知安装、调试维护和安全触达。 | 既有设计记录 确认三层底盘冻结结构；公开 CAD 资料已归档第三层底板 CAD。 | 已外发加工，待到货验收。 |
| MECH-004 | 层间连接 / 通用固定件套装 | 1 套 | 全车机械安装 | 用于三层底板、支撑柱、支架、传感器、急停、电控板、线夹等固定。 | 既有设计记录 确认三层底盘使用立柱 / 支撑柱连接；公开 CAD 资料已归档层间支撑件 CAD。 | 螺丝、螺母、垫片、铜柱等仍待实物装配前确认。 |
| MECH-005 | 驱动板安装柱 / 绝缘垫柱组件 | 2 套 | 下层动力区 → 双路电机驱动板 | 固定两块双路电机驱动板，并保留自然散热空间。 | 既有设计记录 确认驱动板安装在下层动力区，并预留自然散热空间。 | 数量按驱动板孔位确认。 |
| MECH-006 | 急停按钮安装孔位加强件 / 安装座 | 1 | 上层板顶部中后部 | 固定急停按钮并承受按压载荷。 | 既有设计记录 确认急停按钮安装在车体顶部中后部，按钮允许明显凸起，便于快速按下。 | 不单独采购；急停按钮自带安装紧固件，装配时仍需确认承压和防松。 |

---

## 10. 线束与连接辅件层

现有线材包含 22AWG 硅胶线、1007/22AWG 电子线和热缩管。当前线材、线径、UART 端子和采购长度已由 `hardware/wiring/wire_selection_v0_1.md` 初步收束；线材、端子、压接工具、线束固定件、热缩管补充包和标识件均已进入采购待到货状态，并在 P2 装配中完成实物验证。

| 编号 | 缺失硬件 | 数量 | 所属拓扑节点 | 用途 | 缺失依据 | 规格/型号状态 |
|---:|---|---:|---|---|---|---|
| WIRE-001 | 分路保险盒 / 负极汇流排 | 1 套 | 主电源总开关 → 动力/计算/Mid360/传感器控制支路 | 将主开关后的正极输入按电源架构分为动力支路、计算支路、Mid360 独立 12V 感知供电支路和传感器/控制支路，并提供负极汇流。 | 既有设计记录 确认电源至少分为动力支路、计算支路、传感器/控制支路，既有设计记录 进一步确认 Mid360 独立 12V DC-DC 支路；PWR-006 主输入保险仍位于主开关之前，WIRE-001 不替代主输入保险；既有设计记录 确认分路保险盒方案。 | 已到货待验证，分路保险丝值仍待后续负载和线径确认。 |
| WIRE-002 | 大电流电源线连接端子套装 | 1 套 | 主电池/急停/电驱板动力线 | 连接主电池、急停执行器件和电机驱动板的动力线。 | 动力支路采用 3S 电池直供电机驱动板，且急停只切断动力支路。 | 已采购待到货；12AWG、14AWG、18AWG 红黑硅胶线、M8/M6 环形端子、管型端子套装和一进二出大电流分线端子均已采购，仍待到货和实物压接验证。 |
| WIRE-003 | 小信号接线端子套装 | 1 套 | STM32 ↔ 编码器/采样/小信号接口 | 连接编码器、电压采样、电流采样和必要的小信号接口。 | 硬件架构确认四个电机编码器反馈进入 STM32，主电池电压检测和动力支路电流检测进入 STM32。 | 已采购待到货；2.54mm 杜邦母头端子和胶壳已采购，JST-XH 2.54 不采购；22AWG 线材优先使用库存，四芯屏蔽线本轮未采购，编码器延长线后续按需补买。 |
| WIRE-004 | UART 连接线 / 杜邦线 / 端子线组件 | 1 套 | Orin NX ↔ STM32 UART | 建立底盘通信物理链路。 | 既有设计记录 确认 Orin NX 与 STM32 通过 UART 双向通信。 | 已采购待到货；24AWG 三芯屏蔽软线、2.54mm 杜邦母头端子和 3P 胶壳均已采购，仍待到货和实物压接验证。 |
| WIRE-005 | 线束固定辅件套装 | 1 套 | 全车走线分区 | 固定线束，降低振动、刮擦和误拉扯风险。 | 硬件架构待细化项包含更细的走线分区图，后续接线图和装配照片索引需继续补充。 | 已采购待到货；含扎带、线夹、粘贴固定座等，实际固定强度待 P2 装配验证。 |
| WIRE-006 | 热缩管补充包 | 1 套 | 线束端部绝缘与标识 | 补足不同规格热缩管，服务电源线和信号线端部绝缘。 | 现有热缩管状态为已列入现有物料，但规格仍需按实际线径覆盖。 | 已采购待到货；到货后确认规格覆盖 12AWG / 14AWG / 18AWG / 22AWG / 24AWG。 |
| WIRE-007 | 线号管 / 标签纸 | 1 套 | 全车线束标识 | 标记电源支路、信号线、传感器线和调试接口。 | 项目整体成果要求形成可复现、可部署、可维护的硬件工程材料，硬件架构也要求后续形成正式接线图和装配照片索引。 | 已采购待到货；P2 接线时按关键线束和易混接插件两端标记。 |

---

## 11. 工具与装配设备

| 编号 | 缺失硬件 | 数量 | 所属拓扑节点 | 用途 | 缺失依据 | 规格/型号状态 |
|---:|---|---:|---|---|---|---|
| TOOL-001 | 热风枪 | 1 | 线束制作 / 端部绝缘处理 | 用于热缩管收缩、带胶热缩管密封和线束端部绝缘处理。 | 当前主电池入口连接组件需要热缩管 / 带胶热缩管做焊点绝缘和应力缓解；已有工具只有电烙铁、示波器和万用表，未列出热风枪。 | 已到货待验证。 |
| TOOL-002 | 线束端子压接工具套装 | 1 套 | 线束制作 / 端子压接 | 用于环形冷压端子、管型端子、杜邦端子压接，以及剥线、剪线和线束整理。 | 当前端子采购已收束，需要配套压接与剥线工具；不应使用钳子硬夹或焊锡替代压接。 | 已采购待到货；含棘轮式冷压端子压线钳、管型端子压线钳、杜邦小端子压线钳、自动剥线钳、斜口钳、尖嘴钳；JST-XH 2.54 本轮不采购。 |

---

## 12. 按拓扑汇总的最小缺失硬件清单

> 本节用于公开汇总当前仍需验收、装配或验证的硬件条目；采购链接、价格、供应商和内部采购过程不在公开仓库展开。

| 序号 | 拓扑层 | 缺失硬件 | 数量 | 是否 P1.3/P2 前置 | 备注 |
|---:|---|---|---:|---|---|
| 1 | 主电源入口层 | 3S 主电池 | 1 | 是 | 已按 既有设计记录 确认并采购，已到货待验证。 |
| 2 | 主电源入口层 | 主电池电源连接器组件 | 1 套 | 是 | 已按 既有设计记录 确认为 XT60 公头自制主电池入口连接组件，已到货待验证。 |
| 3 | 主电源入口层 | 主输入保险座 / 保险丝 | 4 套 | 是 | 已按 既有设计记录 确认为 ATO / ATC 保险座 + 25A 插片保险丝，已到货待验证。 |
| 4 | 主电源入口层 | 主电源总开关 | 1 | 是 | 已按 既有设计记录 确认为汽车 / 摩托车电瓶断电旋钮开关，已到货待验证。 |
| 5 | 主电源入口层 | 主电池托盘 | 1 | 是 | 已采购待到货；既有设计记录 确认托盘式限位结构。 |
| 6 | 主电源入口层 | 主电池固定绑带 | 2 | 是 | 已采购待到货；既有设计记录 确认托盘 + 绑带固定。 |
| 7 | 动力支路层 | 蘑菇头急停按钮 | 1 | 是 | 已按 既有设计记录 确认为工业面板式 40mm 蘑菇头急停按钮，已到货待验证。 |
| 9 | 动力支路层 | 急停动力切断执行器件 | 1 | 是 | 已按 既有设计记录 确认为 JD2912 12V 40A 四脚汽车继电器，已到货待验证。 |
| 10 | 动力支路层 | 双路电机驱动板 | 2 | 是 | 已按 既有设计记录 确认为 WAYNESTARK WSDC2412D-V3.0，已到货待验证。 |
| 11 | 动力支路层 | JGB-520 带编码器减速电机 | 4 | 是 | 已采购新永泰电机 JGB37-520-12100，已到货待验证。 |
| 12 | 动力支路层 | 轮胎 | 2 | 是 | 现有 2 个，四轮底盘需补足 2 个；补充轮胎已采购并已到货待验证。 |
| 13 | 动力支路层 | 轮毂联轴器 / 电机轮连接件 | 4 | 是 | 已采购并已到货待验证；需匹配电机输出轴与轮毂。 |
| 14 | 动力支路层 | 电机安装座 / 电机固定支架 | 4 | 是 | P2 机械组装前置。 |
| 15 | 计算支路层 | Orin NX 独立 DC-DC 稳压电源模块 | 1 | 是 | 已按 既有设计记录 确认为 IIO-PW936 1-4，已到货待验证。 |
| 16 | 计算支路层 | Orin NX 安装板 / 固定支架组件 | 1 套 | 是 | 已采购待到货；固定高度、绝缘、散热避让和维护可达性待 P2 装配确认。 |
| 17 | 计算支路层 | Orin NX UART 转接/连接线组件 | 1 套 | 是 | 由 WIRE-004 承接；本轮不单独采购额外转接件，P2 实物确认后再判断是否补件。 |
| 18 | 计算支路层 | Orin NX C1902 V1.1 载板 | 1 | 是 | 已确认为 C1902 V1.1 Orin Nano / NX 系列载板，已购买待到货；散热能力、外接 RTC 电池和装车适配待验证。 |
| 19 | 传感器/控制支路层 | 传感器/控制支路 DC-DC 电源模块 | 1 | 是 | 已按 既有设计记录 确认为 5V / 6A DC-DC Buck 降压稳压模块，已到货待验证。 |
| 20 | 传感器/控制支路层 | STM32 控制板 | 1 | 是 | 已按 既有设计记录 确认为 STM32F407VET6 核心板 / 开发板 V5.5，已到货待验证。 |
| 21 | 传感器/控制支路层 | STM32 安装支架 / 固定柱组件 | 1 套 | 是 | 已采购待到货；高度、螺丝长度、绝缘和维护可达性待 P2 装配确认。 |
| 22 | 传感器/控制支路层 | 主电池电压采样模块 | 1 | 是 | 已按 既有设计记录 确认为 Keyes 电压检测模块，已到货待验证。 |
| 23 | 传感器/控制支路层 | 动力支路电流检测模块 | 1 | 是 | 已按 既有设计记录 确认为 ACS712-30A 电流传感器模块，已到货待验证。 |
| 24 | 感知安装层 | Mid360 顶部安装支架 | 1 | 是 | CAD 已冻结，待加工/装配验证。 |
| 25 | 感知安装层 | Mid360 增高立柱 / 支撑柱组件 | 1 套 | 是 | CAD 已冻结，待加工/装配验证。 |
| 26 | 感知安装层 | D435 前向安装支架 | 1 | 是 | CAD 已冻结，待加工/装配验证。 |
| 27 | 感知安装层 | 补光模块 | 1 | 暂缓 | 既有设计记录 确认当前采购批次不采购，保留后续恢复选型可能。 |
| 28 | 感知安装层 | 补光控制模块 | 1 | 暂缓 | 随补光模块暂缓，后续若恢复补光再选型。 |
| 29 | 感知安装层 | 补光模块安装支架 | 1 | 暂缓 | 随补光模块暂缓，后续按灯体尺寸确定。 |
| 30 | 感知安装层 | Mid360 独立 12V DC-DC 稳压模块 | 1 | 是 | 已按 既有设计记录 确认为 UENPO S3 12V 3A / 36W，已到货待验证。 |
| 31 | 底盘机械结构层 | 第一层底板 | 1 | 是 | 已外发加工，待到货验收。 |
| 32 | 底盘机械结构层 | 第二层底板 | 1 | 是 | 已外发加工，待到货验收。 |
| 33 | 底盘机械结构层 | 第三层底板 | 1 | 是 | 已外发加工，待到货验收。 |
| 34 | 底盘机械结构层 | 层间连接 / 通用固定件套装 | 1 套 | 是 | 已采购待到货；三层底板、支撑柱、支架和电控板装配通用。 |
| 35 | 底盘机械结构层 | 驱动板安装柱 / 绝缘垫柱组件 | 2 套 | 是 | 已采购待到货；两块驱动板下层安装并预留散热空间。 |
| 36 | 底盘机械结构层 | 急停按钮安装孔位加强件 / 安装座 | 1 | 否 | 不单独采购；急停按钮自带安装紧固件，装配时仍需确认承压和防松。 |
| 37 | 线束与连接辅件层 | 分路保险盒 / 负极汇流排 | 1 套 | 是 | 已到货待验证；用于主开关后动力、计算、Mid360 独立 12V DC-DC、传感器/控制支路分配；不替代 PWR-006 主输入保险。 |
| 38 | 线束与连接辅件层 | 大电流电源线连接端子套装 | 1 套 | 是 | 已采购待到货；线材、大电流端子和分线端子均已采购，仍待实物压接验证。 |
| 39 | 线束与连接辅件层 | 小信号接线端子套装 | 1 套 | 是 | 已采购待到货；杜邦端子/胶壳已采购，JST-XH 2.54 不采购，四芯屏蔽线本轮未采购。 |
| 40 | 线束与连接辅件层 | UART 连接线 / 杜邦线 / 端子线组件 | 1 套 | 是 | 已采购待到货；三芯屏蔽线、杜邦母头端子和 3P 胶壳均已采购。 |
| 41 | 线束与连接辅件层 | 线束固定辅件套装 | 1 套 | 是 | 已采购待到货；走线固定与防松脱，固定强度待 P2 验证。 |
| 42 | 线束与连接辅件层 | 热缩管补充包 | 1 套 | 是 | 已采购待到货；补足线束端部绝缘规格。 |
| 43 | 线束与连接辅件层 | 线号管 / 标签纸 | 1 套 | 是 | 已采购待到货；便于后续接线图、维护和复现。 |
| 44 | 工具与装配设备 | 热风枪 | 1 | 是 | 已到货待验证；用于热缩管收缩、带胶热缩管密封和线束端部绝缘处理。 |
| 45 | 工具与装配设备 | 线束端子压接工具套装 | 1 套 | 是 | 已采购待到货；用于冷压端子、管型端子、杜邦端子压接和剥线剪线。 |

---

## 13. 当前不应在本清单中强行冻结的内容

以下内容当前只能作为“待选型 / 待细化”，不应在本清单中伪造具体型号：

1. 补光模块已按 既有设计记录 暂缓采购，当前不强行冻结具体电路方案。
2. WIRE-002 / WIRE-003 / WIRE-004 已形成当前采购口径并完成本轮采购，但每个端子的实物匹配、压接质量、线束长度余量、线号标识和线束固定点仍待 P2 装配时确认；WIRE-004 的三芯屏蔽线和杜邦端子/胶壳已采购，JST-XH 2.54 不采购，四芯屏蔽线本轮未采购；WIRE-001 的分路保险丝值仍待后续负载和线径确认。
3. 线束固定点、支撑柱实物组合、螺丝长度、垫片规格、Orin NX 与 STM32 维护可达性、驱动板与电池托盘实物装配余量；D435 与补光模块相对位置待补光恢复选型后再确认。

---

## 14. 安全边界提醒

1. 硬件急停必须独立于软件链路，直接切断动力支路。
2. 急停只切断动力支路，不切断 Orin NX、STM32、传感器和日志记录能力。
3. 人工接管不替代硬件急停，硬件急停仍是最高优先级的物理安全手段。
4. 后续采购和接线图必须保持动力支路、计算支路、传感器/控制支路的分区边界，不得为调试便利绕过急停或削弱电源隔离。

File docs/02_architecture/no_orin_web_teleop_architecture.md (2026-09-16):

# 无 Orin 本机网页控制覆盖层

## 定位

当最终上位机暂不可用时，Project0 使用一个临时、可撤销的本机覆盖层验证 H60 控制链，不改变最终的 ROS2 + H60 架构：

```text
浏览器 -> localhost 后端 -> H60 链路适配器 -> H60
```

浏览器只表达 STOP、DISARM、ARM 请求和受限方向意图；后端负责身份门、短租约、旧请求拒绝、断连停车、日志和故障锁止；H60 继续负责默认失能、显式 ARM、75 ms 非零命令租约、IWDG 与故障撤输出。

## 分层

| 层 | 职责 |
| --- | --- |
| 网页 | 只发受限意图，不生成 PWM、串口帧或生产轮速 |
| localhost 后端 | 独占会话、客户端序号、租约、超时与审计 |
| H60 链路 | 把已批准的高层意图映射为受限协议命令 |
| H60 固件 | 最终 ARM、命令新鲜度、故障和输出安全门 |

## Fail-closed 行为

- 未 ARM、身份漂移、遥测超时或协议错误时拒绝运动；
- 浏览器断开或命令租约过期时发送 STOP/DISARM；
- 方向改变不能直接穿越零点，必须先 STOP 并重新 ARM；
- STOP 未确认、日志写入失败或链路状态未知时锁定故障；
- 恢复连接后不恢复旧命令，旧客户端请求保持失效。

## 公开实现边界

`tools/no_orin_web_teleop/` 公开的是 fake serial 演示、状态机、网页和自动测试。真实设备身份、一次性现场流程和运行授权不进入公开仓库。

## 验证边界

H60-only 架空四轮前进、后退、STOP 与定性断链停车已经形成受限证据，但不覆盖上位机、落地、负载、热、长时、精确停轮时序或完整 H7/H8。

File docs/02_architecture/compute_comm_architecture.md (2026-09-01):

# Compute and Communication Architecture
---

> **当前实现覆盖（DEC-047 / DEC-046）**：Orin NX 是当前主计算机，底层执行控制器为 OpenCTR H60 V3.7。当前主链路、单侧掉电反供电和运动状态机见 `p2_h60_rebuild_baseline.md`。文中的 STM32、急停/继电器和旧“安全链”名称均属于上一平台历史实现。

> **临时可用性边界（2026-09-01）**：Orin NX/C1902 已因电气异常送修，当前不可用于车辆。P2 暂时只推进 H60 本地安全运动与基础前进/后退/停止；感知、ROS2、上位机判断、数据上传和既定 USB 手柄链延期。该临时模式不改变本文件的最终职责架构，也不证明 H60 可直接接 USB 手柄。

## 1. 文档定位

本文档在《项目0系统总架构设计》之下，进一步回答以下问题：

1. Orin NX 与 H60 分别负责什么
2. 各主要设备之间如何通信
3. 主链路与辅助链路如何在计算平台上落位
4. ROS2 主要节点组如何进行粗粒度规划

本文档属于计算与通信架构，因此**只定义** ：

- 计算职责划分
- 通信链路关系
- 节点组落位关系
- 数据流、控制流、状态流的大方向

**不定义**：

- 具体接线方式、物理接口型号
- 具体 ROS2 话题/服务/动作名称
- 具体通信协议字段
- 具体软件包结构与 launch 组织方式
- 具体参数取值和算法实现细节

以上内容应由后续文档承接：

- 软件架构文档
- 接口定义文档
- 硬件架构文档
- 模块实现设计文档

---

## 2. 架构目标与原则

项目0是一个面向教学楼走廊真实场景、以真机闭环为验收标准的具身智能地面移动平台。计算与通信架构必须服务于这一定位，并与系统总架构保持一致。

### 2.1 单主计算平台

系统只有一个明确的主计算中心：**Orin NX**。

### 2.2 单底层执行控制平台

系统只有一个明确的底层执行控制中心：**OpenCTR H60 V3.7**。

### 2.3 上层集中、下层确定

- Orin NX 负责上层系统闭环（感知、定位、导航、任务、运行监测与仲裁、系统管理、数据记录）
- H60 负责底层实时闭环（电机控制、编码器读取、本地超时、看门狗和故障撤 PWM）

这是整份文档最核心的职责划分原则。后续所有通信链路和节点落位均以此为基础。

### 2.4 先支撑迭代一，再承接迭代二

计算与通信架构必须先支撑迭代一单车闭环，再在不推翻主从骨架的前提下承接迭代二增强。

### 2.5 外部操作终端不纳入正式计算节点

当前没有独立急停按钮。人工接管输入按 DEC-018 采用飞智黑武士2手柄，通过 2.4G USB 接收器接入 Orin NX，并由 Orin NX 上的 teleop / 手动控制节点生成运动意图，经运行仲裁后下发到底盘链路。

---

## 3. 计算实体划分

项目0采用"单主计算平台 + 单底层控制平台 + 外设接入"的结构。

### 3.1 Orin NX

系统唯一主计算与主控平台。

承担：

- 感知接入与管理（Mid360、D435、IMU 数据接收与发布）
- 定位、建图、地图管理
- 导航与避障
- 语义导航与任务调度
- 安全监测与上层安全处置
- 系统管理、自检、运行监控
- 数据记录与调试支撑

### 3.2 H60

系统唯一底层执行控制平台。

承担：

- 电机驱动与 PID 速度闭环控制
- 编码器读取与里程计初步计算
- 底盘安全保护（速度限幅、通信超时停车、IWDG 和异常撤 PWM）
- 接收 Orin NX 下发的速度指令
- 向 Orin NX 上传编码器数据与底层状态

### 3.3 外设接入

以下设备直接接入 Orin NX：

| 设备 | 接入方式 | 角色 |
|---|---|---|
| Livox Mid360 | USB/以太网 | 3D激光雷达，提供点云与内置IMU数据 |
| Intel RealSense D435 | USB | 深度相机，提供RGB与深度图像 |

> **D435 在迭代一中的角色说明**：D435 在迭代一中仅作为深度/视觉数据源接入系统，用于辅助感知、数据记录（rosbag2 录制）和调试可视化（RViz2 观测）。**D435 数据在迭代一中不流向 SLAM 节点组，不参与 FAST-LIO2 的定位融合**。迭代二前段才将 D435 视觉/深度信息融入定位系统。

以下设备接入 H60：

| 设备 | 接入方式 | 角色 |
|---|---|---|
| MC520P56 四路编码器 | H60 四路 AB 编码器接口 | 提供四轮原始计数与速度反馈 |
| MC520P56 四路电机 | H60 集成 AT8236 电驱 | 接收本地闭环输出；每路限流与热能力待验 |

### 3.4 IMU 数据来源说明

迭代一中 IMU 数据的主路径为：**Mid360 内置 IMU，通过 Livox ROS2 驱动在 Orin NX 上直接发布** 。

备选外置 IMU 不纳入当前 H60 重建前置；如后续需要，另立 CR/DEC 评估接入和时间同步。

---

## 4. 通信链路定义

### 4.1 Orin NX ↔ H60 主从链路

| 项目 | 说明 |
|---|---|
| 物理链路 | 受掉电反供电保护的 UART；永久接线在 H4 通过后冻结 |
| 协议 | 版本 + 长度 + 会话/序号 + 数据 + CRC + 状态/故障帧 |
| 下行数据（Orin NX → H60） | ARM/DISARM/STOP、A/B/C/D 四通道 `int16 mm/s` 轮缘线速度目标、心跳；物理轮映射须经 H6 实测冻结 |
| 上行数据（H60 → Orin NX） | 四轮编码器/轮速、VIN、状态机、故障和固件版本 |
| 通信频率 | 建议 50-100Hz |
| 异常处理 | H60 本地短超时撤 PWM；非法/过期/CRC 错帧失效导向；IWDG 与异常入口先停车 |

### 4.2 感知接入链路

| 传感器 | 物理接口 | 接入平台 | ROS2 驱动 | 数据流向 |
|---|---|---|---|---|
| Mid360 | USB/以太网 | Orin NX | livox_ros_driver2 | → SLAM节点组、导航节点组、数据记录节点组 |
| D435 | USB | Orin NX | Intel RealSense ROS2 Wrapper | → 数据记录节点组、调试可视化（迭代一）；迭代二增加→SLAM节点组 |
| IMU（主路径） | Mid360内置 | Orin NX（Livox驱动发布） | livox_ros_driver2 | → SLAM节点组 |

### 4.3 停止、失能与人工接管通信路径

STOP/DISARM、底层超时停车和人工接管在通信层面的落位必须明确：

| 能力 | 通信路径 | 说明 |
|---|---|---|
| **手柄人工接管** | 飞智黑武士2手柄 → 2.4G USB 接收器 → Orin NX → 手动控制节点 → 运行仲裁 → 底盘桥接 → 受保护 UART → H60 | 人工输入经版本化协议和显式 ARM 会话下发；不采用航模接收机直连底层控制器 |
| **STOP / DISARM** | Orin NX 运行仲裁 → 底盘桥接 → 受保护 UART → H60 | 检测到异常或人工请求后发送 STOP/DISARM；H60 仍以本地超时、IWDG 和故障撤 PWM 兜底 |
| **人工断电** | 操作者 → 外置主开关 → 整车电源 | 当前无独立硬件急停；主开关只作人工断电处置，不经过通信且不称急停 |

### 4.4 数据记录链路

rosbag2 和 ROS2 标准日志统一运行在 Orin NX 上。录制范围覆盖：

- 传感器原始数据话题（Mid360 点云、D435 RGB/深度、IMU）
- 里程计与定位结果话题
- 导航路径与速度话题
- 任务状态话题
- 停止、失能、故障、接管事件与系统状态话题

按 DEC-045，数据记录与长期归档采用分层链路：

1. 现场 rosbag、日志和临时地图先写入 Orin NX 内置 512GB NVMe；
2. 停止录制后检查数据有效性，再执行筛选、裁剪或压缩；
3. 通过 USB 将关键数据复制到 2TB 便携式机械硬盘；
4. 完成回放抽检和 SHA-256 校验后，才能清理 Orin 上的临时数据；
5. U 盘只用于换机和日常小文件周转，不承担 Project0 原始数据长期归档。

外置机械硬盘不进入实时数据通路，也不作为运动中 rosbag 主录制盘。归档复制属于测试结束后的维护操作，不得影响控制、运行仲裁、感知或导航主链路。

### 4.5 通信链路总览图（文字描述）

```
外部操作者
  ├─ 外置主开关 ──→ [人工整车断电；不称急停]
  └─ 飞智黑武士2手柄 ──→ 2.4G USB 接收器 ──→ Orin NX（teleop / 手动控制节点）

Orin NX（主计算平台）
  ├─ USB/以太网 ←── Mid360（点云 + IMU）
  ├─ USB ←── D435（RGB + 深度）
  ├─ ROS2: teleop / 手动控制节点 ──→ cmd_vel ──→ 底盘桥接节点
  ├─ 受保护 UART ←→ H60（ARM/STOP/速度指令↓ / 编码器+VIN+状态+故障↑）
  ├─ ROS2 内部通信（节点组之间）
  └─ 内置 NVMe 录制 ──→ 筛选 / 压缩 ──USB──→ 外置机械硬盘归档

H60（底层控制平台）
  ├─ 四路定时器 ←── MC520 AB 编码器
  ├─ 四路 PWM ──→ 板载 AT8236 ──→ MC520 电机
  └─ UART ←→ Orin NX
```

---

## 5. 系统总架构在计算平台上的落位

### 5.1 主链路落位

系统总架构定义的五层主链路在计算平台上的落位关系：

| 主链路层级 | 计算平台 | 说明 |
|---|---|---|
| 执行层 | H60 | 四路电机控制、编码器读取、本地超时、看门狗和故障撤 PWM 在 H60 实时闭环中完成 |
| 感知层 | Orin NX | 传感器驱动与数据发布统一在 Orin NX 上 |
| 空间认知层 | Orin NX | FAST-LIO2 建图/定位运行在 Orin NX 上 |
| 行动规划层 | Orin NX | Nav2 导航框架运行在 Orin NX 上 |
| 任务决策层 | Orin NX | BehaviorTree.CPP + 语义导航逻辑运行在 Orin NX 上 |

### 5.2 辅助链路落位

| 辅助链路 | 计算平台 | 说明 |
|---|---|---|
| 运行约束链路 | H60（限幅、超时、IWDG、故障撤 PWM）+ Orin NX（监测、STOP/DISARM、接管仲裁）+ 主开关人工断电 | 当前无独立急停/继电器；不作产品安全能力声明 |
| 系统管理链路 | Orin NX | 启停管理、状态管理、自检、配置管理、运行监控统一在 Orin NX |
| 数据记录链路 | Orin NX | rosbag2 录制和日志输出统一在 Orin NX |

---

## 6. ROS2 节点组粗粒度规划

以下为 Orin NX 上运行的 ROS2 节点组规划。**本节只定义节点组及其系统角色，不定义组内各节点的具体拆分和职责——组内节点拆分由软件架构文档承接** 。

| 节点组 | 运行平台 | 系统角色 | 对应总架构模块 |
|---|---|---|---|
| 感知接入节点组 | Orin NX | 运行传感器驱动，发布点云、图像、深度、IMU 等感知数据 | 感知模块 |
| SLAM 节点组 | Orin NX | 运行 FAST-LIO2，完成建图与定位 | 空间认知模块 |
| 导航节点组 | Orin NX | 运行 Nav2 框架，完成全局路径规划、局部避障、路径跟踪与代价地图管理 | 行动规划模块 |
| 任务决策节点组 | Orin NX | 运行 BehaviorTree.CPP 与语义导航逻辑，完成任务管理与语义目标转换 | 任务决策模块 |
| 底盘桥接节点组 | Orin NX | 负责 Orin NX 侧的 UART 通信处理，将 ROS2 速度指令转为串口数据下发，将串口上传数据转为 ROS2 话题发布 | 执行模块（Orin NX 侧桥接） |
| 运行仲裁节点组 | Orin NX | 监控定位/感知/导航/通信/电压等状态，检测异常，发布 STOP/DISARM 并仲裁手动/自动运动意图 | 运行约束模块 |
| 系统管理节点组 | Orin NX | 管理系统模式、状态、自检、启动流程、参数配置与运行监控 | 系统管理模块 |
| 数据记录节点组 | Orin NX | 运行 rosbag2 录制与日志管理 | 数据记录与复盘模块 |

> H60 上不运行 ROS2 节点，运行运动控制固件，负责四路电机控制、编码器读取、本地状态机、超时/IWDG/故障撤 PWM 和 UART 通信。仓库现有 STM32 源码只作迁移骨架与历史证据。

---

## 7. 数据流、控制流与状态流大方向

### 7.1 数据流

```
Mid360 ──点云+IMU──→ 感知接入节点组 ──→ SLAM节点组 ──→ 导航节点组
D435 ──RGB+深度──→ 感知接入节点组 ──→ 数据记录节点组（迭代一）
H60 ──编码器+VIN+状态+故障──→ 底盘桥接节点组 ──→ SLAM节点组 / 导航节点组 / 安全节点组
```

### 7.2 控制流

```
任务决策节点组 ──导航目标──→ 导航节点组 ──速度指令──→ 安全仲裁──→ 底盘桥接节点组 ──受保护 UART──→ H60 ──PWM──→ 电机
```

### 7.3 状态流

```
各节点组 ──运行状态──→ 系统管理节点组（汇总系统状态）
各节点组 ──异常状态──→ 运行仲裁节点组（检测异常、触发 STOP/DISARM）
各节点组 ──话题数据──→ 数据记录节点组（全程录制）
```

---

## 8. 迭代视角下的计算与通信架构稳定性

### 8.1 迭代一中的作用

在迭代一阶段，本架构支撑固定场景最小闭环：

- Orin NX 运行感知、SLAM、导航、任务、运行仲裁、管理和记录逻辑
- H60 运行四路电机控制、编码器读取、本地超时、看门狗和故障撤 PWM
- UART 连接上下位机
- Mid360 提供点云与 IMU 数据用于 FAST-LIO2
- D435 接入但仅用于记录和调试，不参与定位融合
- 飞智黑武士2手柄通过 2.4G USB 接收器接入 Orin NX，由 teleop / 手动控制节点生成运动意图，经运行仲裁与底盘桥接下发到 H60

### 8.2 迭代二中的变化

迭代二在不改变主从骨架的前提下承接增强：

- **迭代二主线**（优先推进）：D435 数据流从"仅记录"扩展为"流向 SLAM / 定位相关节点组参与视觉或深度辅助融合"；编码器里程计从"独立发布"扩展为"融入定位系统"；这些变化均在 Orin NX 内部的 ROS2 节点组之间发生，不改变 Orin NX ↔ H60 的通信结构
- **迭代二后续增强**（在融合主线基本完成后推进）：可能新增外挂回环检测、地图一致性修正与退化处理逻辑；IEKF / FAST-LIO 核心研究仅作为有余力时的候选深化项，同样不改变计算与通信骨架

**结论：迭代二所有增强均为 Orin NX 内部节点组的能力增强或数据流扩展，主从架构骨架不变，通信链路不变。**

---

## 9. 架构边界声明

### 9.1 本文档回答

- Orin NX 和 H60 分别承担什么职责
- 传感器归谁接入
- 控制与反馈链路如何贯通
- 安全相关通信路径如何落位
- ROS2 主要节点组如何粗粒度落位
- 数据流、控制流、状态流大方向

### 9.2 本文档不回答

- 具体物理接口与协议字段
- 具体话题/服务/动作命名
- 具体软件包结构
- 具体 launch 组织方式
- 具体参数与实现细节

这些内容应由后续文档承接：

- 软件架构文档
- 接口定义文档
- 硬件架构文档
- 模块实现设计文档

---

## 10. 总结

项目0计算与通信架构可以概括为：

> 项目0采用 Orin NX 主计算机与 OpenCTR H60 V3.7 底层执行控制器的主从架构。感知、导航、任务、人工/自动仲裁、系统管理与记录位于 Orin NX；四路电机/编码器闭环、本地限幅、超时、看门狗与故障撤 PWM 位于 H60。Mid360 和 D435 接入 Orin NX；运动指令通过受保护、单侧掉电不反灌的 UART，以版本化协议和显式 ARM 会话下发 H60。当前无独立急停/继电器或反馈 GPIO；任一侧重启或通信恢复都不得自动恢复运动。

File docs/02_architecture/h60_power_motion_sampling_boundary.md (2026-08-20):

# H60 当前电源、运动约束与采样边界

> 状态：公开数字基线 / 尚未形成实物、上电或运动准入
> 更新：2026-08-20

## 当前电源树

```text
3S 主电池
-> 25A 主输入保险
-> 外置主电源开关
-> 带支路保护的分配节点
   +-> H60 支路 -> H60 J1 -> 4 × MC520P56
   +-> Orin 支路 -> 12V DC-DC -> Orin NX
   +-> Mid360 支路 -> 12V DC-DC -> Mid360
```

H60、Orin 和 Mid360 的支路保险值必须结合线径、端子、稳态电流、峰值电流和温升证据冻结，不能沿用上一平台路号或凭经验直接放大。

## 当前不存在的硬件

当前 H60 新车不安装：

- 独立蘑菇急停按钮；
- 急停继电器或接触器；
- 继电器线圈支路；
- 急停状态 GPIO；
- Keyes 外置电压模块；
- ACS712 或其他车载电流采样模块。

上一 STM32 小车中的对应器件、接线和测试保存在历史资料中。主开关用于人工断开整车电源；当前车辆没有独立急停装置。

## 停车、失能与恢复

1. H60 上电、复位、棕断恢复和看门狗复位后保持 `DISARMED / PWM=0`。
2. 只有自检、链路、故障状态、命令新鲜度和输入回中满足要求后，新会话显式 ARM 才能使能运动。
3. STOP、DISARM、通信超时、非法帧、序号回退、IWDG 和固件异常入口必须先撤销四路 PWM。
4. 速度、加速度、反转和首次占空比采用保守限值；换向必须经过零输出。
5. H60、Orin 或 UART 链路重启后不得自动恢复运动。
6. 首次动力测试必须架空、低能量、轮周净空并由操作者持续监看；落地低速必须在 H0-H7 全部通过后另行授权。

当前没有独立硬件急停，因此测试区域、速度、监护、主开关可达性和逐门准入必须更保守。楼梯口、边缘区域、电梯口和排水槽附近不得作为早期运动测试区。

## UART 单侧掉电

H60 或 Orin 的支路故障、维护断电和启动时序都可能形成单侧上电。永久连接前必须分别验证两侧掉电组合，测量对侧电源轨、UART 引脚和反灌电流；必要时采用掉电高阻缓冲或数字隔离。反供电门未关闭前，不制作永久运动线束。

## 采样边界

- 当前车载采样只有 H60 `PC0` VIN ADC；完成多点校准后才能用于状态上报。
- VIN 只代表 H60 支路上电期间的电压，不是独立电池监测，也不能在 H60 失电时持续观测。
- 当前没有车载电流遥测。外部仪表在台架中得到的电流只作为测试证据。
- H60 驱动内部限流或过流保护不能被描述为可记录的电流采样功能。

## 未关闭门

实物版本、三支路保护、线束和端子、UART 反供电、运动控制固件、VIN 校准、四路电流与温升、回生母线峰值、停车距离、机械试装和落地低速均未完成。精确执行顺序见 [H0-H8 重建验收计划](../06_testing/p2_h60_mc520_rebuild_acceptance_plan_2026-08-16.md)。

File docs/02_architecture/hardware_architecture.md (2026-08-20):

# hardware_architecture.md

> **当前实现覆盖（2026-08-20）**：当前硬件基线为 H60 V3.7 + 4×MC520P56_12V + 65 mm 轮和两层整车 CAD。本文第 2–15 节保留 P1 与上一实车平台的详细展开；其中出现的独立 STM32、双 WSDC2412D、JGB37-520、ACS712、Keyes、急停/继电器、CTRL-001 和三层底盘均为历史，不能作为当前采购、接线、CAD 或验收输入。当前实现以 `p2_h60_rebuild_baseline.md`、`hardware/bom.md` 和第 16 节为准。

## 1. 文档定位

本文档属于项目0在 P1 阶段的系统架构设计输出物之一，放置在：

```text
docs/02_architecture/hardware_architecture.md
```

本文档与以下架构文档并列管理：

```text
docs/02_architecture/system_architecture.md
docs/02_architecture/compute_comm_architecture.md
docs/02_architecture/power_architecture.md
docs/02_architecture/software_architecture.md
docs/02_architecture/interface_definition.md
```

本文档用于承接系统总架构中未展开的硬件实现层内容，定义项目0迭代一小车的硬件基线方案。

本文档的目标不是替代实物装配图、BOM、接线图、原理图或 CAD 图，而是为迭代一单车系统提供可执行、可联调、可验收的硬件架构基线。

本文档重点回答以下问题：

1. 小车由哪些主要硬件模块组成；
2. 这些硬件模块在整车中分别承担什么职责；
3. 主电源、动力、计算、传感器/控制和人工断电处置之间如何分层；
4. Orin NX、STM32、传感器、电驱、电机之间如何形成硬件链路；
5. 哪些内容属于当前 P1 架构级确定项，哪些留到后续 BOM、接线图和 P2-P3 实物联调中细化。

---

## 2. 阶段归属与依赖关系

项目0总体流程采用 P0-P10 分阶段推进方式。

当前本文档属于 P1 阶段输出物，服务于以下后续阶段：

- P2：底盘机械组装、急停安装、人工接管链路建立、基础运动验证；
- P3：Mid360、D435 的实际安装、接入、标定、建图与定位验证；补光模块按后续恢复条件另行展开；
- P4-P6：导航、安全、系统管理、运行监控、自检、数据记录与系统集成验收；
- P7-P10：在迭代一硬件基线不推翻的基础上进行传感器融合、鲁棒性增强和语义导航增强。

本文档直接依赖：

- 项目定义、迭代一功能清单与功能条目；
- `docs/02_architecture/system_architecture.md`；
- `docs/02_architecture/compute_comm_architecture.md`；
- `docs/02_architecture/power_architecture.md`。

本文档直接支撑：

- 内部采购执行记录；
- `hardware/bom.md`；
- 用户重新设计的新整车 CAD 已导入 `hardware/cad/current_vehicle_v0_2/`；数字几何复审已通过，部分被动结构件已委托加工，但尚未交付、试装或形成实物验收冻结包；旧三层结构只作上一平台历史；
- 后续接线图、装配照片索引和 P2-P6 测试文档。

---

## 3. 硬件架构设计目标

项目0硬件架构在迭代一阶段应满足以下目标。

### 3.1 支撑迭代一最小闭环成立

硬件架构必须优先服务于迭代一平台主干能力成立，包括：

- 底盘可控运动；
- 编码器反馈与基础里程计；
- Orin NX 与 H60 稳定通信，且两端异步掉电时不得反供电；
- Mid360 接入与建图定位；
- D435 接入与前向辅助感知；
- 硬件急停与人工接管；
- H60 VIN 电压采样校准与外部整车电流验收测量；
- 补光接口与安装空间预留（SENS-004 / SENS-005 / SENS-006 当前 P1.3 采购批次暂缓）；
- 后续数据记录、系统管理、安全状态上报。

### 3.2 保持单人可落地

项目0由单人 solo 完成，因此硬件架构必须避免在 P1-P2 阶段引入过高机械复杂度或电气复杂度。

硬件路线优先采用：

- 现成底盘板 / 通用板材；
- 用户重新设计、可维护并满足新轮系和电气分区的新车体结构；
- 常见 DC-DC 模块；
- 常见电驱板；
- 可购买或简单制作的支架；
- 可逐步调试、可逐步替换的模块化结构。

### 3.3 保持安全底线

项目0运行于真实室内走廊环境，存在楼梯口、边缘区域、电梯口、夜间弱光、排水槽等风险区域。

硬件架构必须保留以下安全底线：

- 硬件急停独立于软件链路；
- 上一过渡方案曾要求急停继电器只切断 H60 正极，不切断 Orin NX、Mid360 和日志记录能力；该方案已废弃；
- H60 保持底层限幅、通信超时停车、上电默认禁能和底层状态上传能力；
- Orin NX 保持上层安全管理、系统管理和数据记录能力；
- 主电池电压经 H60 VIN ADC 进入底层状态；首版整车电流使用外部钳表或串联功率计验收。

### 3.4 支撑后续成果表达

硬件架构应便于后续展示、解释、拍照、录制视频和写入报告。

因此，整车布局应尽量做到：

- 模块边界清楚；
- 走线方向可解释；
- 上下层职责明确；
- 传感器安装位置合理；
- 安全链路可被单独说明；
- 后续接线图、BOM、照片和测试记录能够与本文档对应。

---

## 4. 整车硬件总拓扑图

本文档新增并引用整车硬件总拓扑图，作为项目0迭代一小车的模块级硬件结构基线。

图源文件：

```text
docs/02_architecture/diagrams/vehicle_hardware_topology.drawio
```

该图表达以下内容：

1. 主电池进入主电源入口后，经整车电源分配拆分为动力支路、计算支路、传感器/控制支路和 Mid360 独立 12V 感知供电支路；
2. 动力支路经硬件急停回路后，为左右两块双路电机驱动板供电；
3. 左右两块电驱板分别驱动四个电机；
4. 四个电机的编码器反馈进入 STM32；
5. 主电池电压检测、动力支路电流检测、急停状态、电驱板故障状态进入 STM32；
6. STM32 通过 UART 与 Orin NX 双向通信；
7. Orin NX 通过以太网接入 Mid360，通过 USB 接入 D435 和 2.4G USB 接收器，其中 D435 通过 Orin NX USB 口取电；
8. 补光能力仅保留后续控制与安装扩展口径，SENS-004 / SENS-005 / SENS-006 当前 P1.3 采购批次暂缓；
9. 整车机械平台承载主电池、电驱板、Orin NX、STM32、Mid360、D435 和急停按钮等关键硬件。

该图属于模块级硬件拓扑图，不是最终接线图。

---

## 5. 已确认的硬件决策

基于当前阶段已经确认的方案，项目0迭代一硬件架构采用以下硬件决策。

### 5.1 底盘形式

底盘采用四轮驱动底盘。

系统控制抽象采用左右两侧等效差速控制，即：

- 左侧电机组；
- 右侧电机组；
- 上层仍使用线速度与角速度形式表达运动意图；
- 底层由 H60 的四路电驱和编码器闭环负责转换为实际电机控制。

迭代一不引入复杂四轮独立高级控制。

### 5.2 车体结构

旧平台曾收束为三层底盘冻结结构，相关 CAD 与装配结果完整保留为历史证据；当前 H60 重建基线已解除该结构的现行加工基线身份。

新车体由用户重新设计，必须围绕 H60、四个 MC520P56 套件、65mm 轮、主保险/主开关、受保护支路、Orin NX、Mid360、D435 和可维护线束重新冻结。仓库已导入 `current_vehicle_v0_2` 的 28 个 STEP；第二轮数字复审确认全部 B-Rep 有效，轴距 `170 mm`、轮距 `184.16 mm` 采用用户最新口径，D435 水平安装且两层底板具有 6 根层间支柱孔位。用户已委托两层铝板、D435 支架和 Mid360 平台加工；新车体结构状态保持待交付、试装、质量/重心、线束、维护与实物公差验收。

### 5.3 主计算平台

主计算平台采用：

```text
Jetson Orin NX 16GB
```

Orin NX 作为 ROS2 主业务承载平台，负责：

- 传感器接入；
- 底盘桥接；
- 定位与建图；
- 地图管理；
- 导航与避障；
- 语义导航；
- 任务管理；
- 安全管理；
- 系统管理；
- 数据记录与复盘。

### 5.4 底层控制平台

底层控制平台采用：

```text
STM32
```

STM32 负责：

- 接收 Orin NX 下发的速度指令；
- 输出 PWM / DIR / EN 控制电机驱动板；
- 读取四个电机编码器；
- 进行底层速度闭环；
- 采集主电池电压；
- 采集动力支路电流；
- 读取急停状态；
- 读取电驱板故障状态；
- 实现通信超时停车；
- 上传底盘状态、编码器、轮速、电压、电流、急停状态和异常标志。

### 5.5 电机驱动方案

迭代一采用：

```text
两块双路电机驱动板
```

两块电驱板分别服务左右两侧或四个电机通道。

电驱板与 STM32 的基本接口为：

```text
STM32 → 电驱板：PWM / DIR / EN
电驱板 → STM32：FAULT / DIAG，若驱动板支持
```

电机驱动板选型时优先考虑：

- 支持当前主电池电压范围；
- 连续电流和峰值电流有足够余量；
- 支持 PWM / DIR 控制；
- 支持 EN / ENABLE 使能；
- 支持过流保护；
- 支持过温保护；
- 支持欠压保护；
- 支持 FAULT / DIAG 故障输出；
- 便于安装在下层动力区；
- 便于散热和接线。

### 5.6 电机与编码器

四个电机分别为：

- 左前电机；
- 左后电机；
- 右前电机；
- 右后电机。

四个电机均应具备编码器反馈。

编码器反馈进入 STM32，用于：

- 轮速计算；
- 速度闭环；
- 基础里程计；
- 底盘状态反馈；
- 后续导航和定位辅助；
- P2 底盘调试与验收。

### 5.7 主传感器

主传感器采用：

```text
Livox Mid360
```

Mid360 安装于车体顶部接近几何中心的位置，优先保证视场，允许明显高出上层板。

Mid360 是迭代一定位建图主传感器。

### 5.8 辅助视觉传感器

辅助视觉传感器采用：

```text
Intel RealSense D435
```

D435 前向安装，作为：

- 前向 RGB-D 辅助感知；
- 调试观察数据源；
- 数据记录来源；
- 后续迭代二多传感器融合增强预留基础。

迭代一阶段 D435 不作为 FAST-LIO2 主融合输入。

### 5.9 补光模块

SENS-004 补光模块、SENS-005 补光控制模块、SENS-006 补光模块安装支架在当前批次暂缓。

当前架构在 D435 附近保留弱光 / 夜间场景的扩展位置；补光模块属于后续选配，不在当前采购、安装和验收清单中。

后续若暗光实测表明需要补光，应在对应 CR / DEC 约束下重新确认灯体、控制器件、安装方式和测试要求。

### 5.10 人工接管方案

人工接管方案采用：

```text
飞智黑武士2手柄 + 2.4G USB 接收器
```

链路为：

```text
飞智黑武士2手柄
→ 2.4G USB 接收器
→ Orin NX
→ teleop / 手动控制节点
→ cmd_vel
→ 底盘桥接
→ UART
→ STM32
→ 电机驱动板
→ 电机
```

2.4G USB 接收器作为 Orin NX 的 USB 外设，由 Orin NX 的 USB 口接入，不作为独立低压负载直接挂到传感器/控制支路 DC-DC 下。

### 5.11 硬件急停方案

急停按钮布置于车体顶部中后部，明显凸起，便于人跟车时快速拍下。

硬件急停回路为纯硬件链路：

```text
动力支路
→ 硬件急停回路
→ 左电驱板 / 右电驱板
```

硬件急停回路的作用是切断电机驱动板供电。

急停动作不经过 Orin NX、STM32、ROS2 或 UART。

急停只切断动力支路，不切断：

- Orin NX；
- STM32；
- Mid360；
- D435；
- 后续补光控制小信号预留；
- 电池电压检测；
- 数据记录能力；
- 系统状态上报能力。

急停状态应作为检测信号回传至 STM32，再通过 UART 上报 Orin NX，用于系统状态显示、日志记录、安全事件记录和后续测试验收。

### 5.12 电源监测与动力监测

迭代一确定实现以下采样 / 检测：

1. 主电池电压检测；
2. 电驱 / 动力支路总电流检测；
3. 四路编码器反馈；
4. 急停状态检测；
5. 电驱板 FAULT / DIAG 检测，若驱动板支持；
6. 电驱板 EN 使能控制，若驱动板支持。

迭代一不做以下内容：

1. 单个电机电流检测；
2. 高精度 SOC；
3. 剩余续航预测；
4. 计算支路 DC-DC 在线电压采样；
5. 传感器/控制支路 DC-DC 在线电压采样；
6. 低压支路电流在线采样；
7. 复杂 EMI 监测；
8. 多级冗余供电监测。

---

## 6. 整车分层布局原则

三层底盘采用：

```text
第一层：底层动力与主电源
第二层：中层控制、电源分配与线束过渡
第三层：上层计算、感知安装与安全触达
```

的分层布局思路。具体孔位、外形和支撑件以上一平台三层底盘冻结 CAD 包为准。

### 6.1 第一层：底层动力与主电源

第一层优先放置或承接：

- 主电池；
- 主电源入口；
- 主保护器件；
- 总开关；
- 电源分配；
- 硬件急停回路相关动力走线；
- 两块双路电机驱动板；
- 动力支路电流检测模块；
- 计算支路 DC-DC；
- 传感器/控制支路 DC-DC。

第一层布局原则：

1. 重物尽量靠下；
2. 高电流动力线尽量短；
3. 电驱板靠近电池和电机线束出口；
4. 电驱板保留自然散热空间；
5. 不让高电流动力线穿越上层计算区；
6. 为后续保险、端子、接插件和接线图细化预留空间。

### 6.2 第二层：中层控制、电源分配与线束过渡

第二层优先放置或承接：

- STM32；
- 传感器/控制支路相关模块；
- 电源分配与局部固定；
- UART、采样线和状态线过渡；
- 线束固定、转接和维护空间。

第二层布局原则：

1. STM32 靠近底层控制与采样线入口；
2. UART、电源线、调试线应便于插拔；
3. 大电流线和小信号线尽量分区固定；
4. 保留必要的线束弯折半径和接插件操作空间；
5. 便于单人调试和问题定位。

### 6.3 第三层：上层计算、感知安装与安全触达

第三层和顶部 / 前向区域放置：

- Orin NX；
- Mid360；
- D435；
- 2.4G USB 接收器；
- 调试接口；
- 补光模块后续预留空间（当前 P1.3 采购批次暂缓）；
- 急停按钮。

第三层布局原则：

1. Mid360 优先保证视场；
2. D435 前向无遮挡；
3. 后续恢复补光时，补光模块优先靠近 D435；
4. 急停按钮明显、可触达；
5. 急停按钮需要兼顾防误触；
6. 传感器支架不在 P1 阶段做复杂定制。

---

## 7. 供电拓扑原则

整车采用单主电池统一供能。

主电池经主电源入口、主保护器件和总开关后进入整车电源分配。

整车供电分为以下主支路：

```text
动力支路
计算支路
传感器/控制支路
Mid360 独立 12V 感知供电支路
```

### 7.1 动力支路

动力支路为：

```text
主电池
→ 主电源入口 / 主保护 / 总开关
→ 电源分配
→ 动力支路
→ 硬件急停回路
→ 动力支路电流检测
→ 左右两块电机驱动板
→ 四个电机
```

动力支路受硬件急停控制。

### 7.2 计算支路

计算支路为：

```text
主电池
→ 主电源入口 / 主保护 / 总开关
→ 电源分配
→ 计算支路 DC-DC
→ Orin NX
```

计算支路不受硬件急停切断。

### 7.3 传感器/控制支路

传感器/控制支路为：

```text
主电池
→ 主电源入口 / 主保护 / 总开关
→ 电源分配
→ 传感器/控制支路 DC-DC
→ STM32 / 主电池电压采样 / ACS712 信号侧 / 急停与电驱状态输入 / 预留小信号接口
```

传感器/控制支路不受硬件急停切断。

D435 通过 Orin NX USB 口接入并取电，不由 CTRL-001 传感器/控制支路 DC-DC 供电。补光模块当前 P1.3 采购批次暂缓，CTRL-001 不承担补光灯体供电。

### 7.4 Mid360 独立 12V 感知供电支路

Mid360 独立 12V 感知供电支路为：

```text
主电池
→ 主电源入口 / 主保护 / 总开关
→ 电源分配
→ Mid360 支路保险
→ Mid360 独立 12V 升降压 DC-DC
→ Mid360
```

Mid360 数据链路仍通过一分三线以太网接入 Orin NX 载板 RJ45。该供电支路不受硬件急停切断，不与 Orin NX 计算支路 DC-DC 或传感器/控制支路 DC-DC 共用。

### 7.5 2.4G USB 接收器供电边界

2.4G USB 接收器通过 Orin NX 的 USB 口接入并供电，不作为传感器/控制支路 DC-DC 的独立负载。

### 7.6 主电池电压检测

主电池电压检测链路为：

```text
主电池
→ 主电池电压检测模块
→ STM32 ADC
→ UART
→ Orin NX
```

该链路用于：

- 低电量告警；
- 运行准入；
- 低电量保护；
- 系统状态显示；
- 数据记录；
- 后续 P6 安全验收。

---

## 8. 计算、控制与通信链路

Orin NX 与 STM32 之间采用 UART 双向通信。

### 8.1 Orin NX 到 STM32

Orin NX 到 STM32 的下行逻辑流包括：

- 速度指令；
- 停车指令；
- 控制模式；
- 软件安全停车意图；
- 人工接管指令。

### 8.2 STM32 到 Orin NX

STM32 到 Orin NX 的上行逻辑流包括：

- 编码器数据；
- 轮速；
- 底盘状态；
- 电池电压；
- 动力支路电流；
- 急停状态；
- 电驱故障状态；
- 通信状态；
- 异常标志。

### 8.3 STM32 到电驱板

STM32 到电驱板的控制信号包括：

```text
PWM
DIR
EN / ENABLE
```

### 8.4 电驱板到 STM32

电驱板到 STM32 的反馈信号包括：

```text
FAULT / DIAG
```

是否接入取决于最终电驱板硬件能力。

---

## 9. 感知硬件链路

### 9.1 Mid360

Mid360 接入 Orin NX。

物理链路为：

```text
Mid360 → USB / 以太网 → Orin NX
```

Mid360 用于迭代一主定位建图链路。

### 9.2 D435

D435 接入 Orin NX，并通过 Orin NX USB 口取电。

物理链路为：

```text
D435 → USB（数据与取电）→ Orin NX
```

D435 用于前向辅助视觉 / 深度感知、调试和数据记录。

### 9.3 补光模块

补光模块当前不作为 P1.3 必购、必装、必测硬件。SENS-004 / SENS-005 / SENS-006 当前 P1.3 采购批次暂缓，架构仅保留后续弱光 / 夜间场景扩展可能。

后续恢复补光选型时，控制方式可重新确认，例如：

```text
Orin NX / STM32 控制意图
→ 补光控制模块
→ 补光模块
```

在未重新开启选型前，补光灯体不挂载到 CTRL-001 传感器/控制支路 DC-DC 下。

---

## 10. 人工接管链路

人工接管硬件链路为：

```text
飞智黑武士2手柄
→ 2.4G USB 接收器
→ Orin NX
→ teleop / 手动控制节点
→ cmd_vel
→ 底盘桥接
→ UART
→ STM32
→ 电驱板
→ 电机
```

人工接管不替代硬件急停。

硬件急停仍是最高优先级的物理安全手段。

---

## 11. 安全硬件链路

项目0迭代一硬件安全链路由三层组成：

1. 纯硬件急停；
2. STM32 底层保护；
3. Orin NX 上层安全监控。

### 11.1 纯硬件急停

硬件急停独立于软件，直接切断动力支路。

### 11.2 STM32 底层保护

STM32 负责：

- 速度限幅；
- 通信超时停车；
- EN 使能控制；
- 编码器反馈读取；
- 电压、电流、急停状态和电驱故障状态采集；
- 底层状态上传。

### 11.3 Orin NX 上层安全监控

Orin NX 负责：

- 安全状态聚合；
- 系统模式管理；
- 软件侧安全停车；
- 日志记录；
- 运行监控；
- 后续 P4-P6 安全联调。

---

## 12. 与电源架构的边界

电源架构回答：

```text
谁给谁供电
电源分为哪些支路
急停切断哪条支路
哪些状态需要提供给系统管理
```

硬件架构回答：

```text
这些硬件模块在整车中如何组织
它们放在哪个物理层
哪些模块之间存在硬件链路
哪些内容留到后续接线图和 BOM 中细化
```

因此，本文档不替代 `power_architecture.md`，而是在电源架构基础上给出整车硬件组织方式。

---

## 13. 与采购清单和 BOM 的关系

本文档给出模块级硬件基线。

内部采购执行记录应基于本文档进一步展开：

- 已有硬件；
- 缺失硬件；
- 数量；
- 规格；
- 优先级；
- 购买链接；
- 到货状态；
- 预算。

`hardware/bom.md` 应基于本文档和采购清单进一步展开：

- 物料名称；
- 数量；
- 关键参数；
- 用途；
- 所属模块；
- 采购 / 到货 / 验证状态；
- 依据来源。

---

## 14. 上一平台当时版本未细化内容

为符合迭代一“先平台成立”的目标，本版本硬件架构暂不细化以下内容：

1. 每个安装孔位的文字展开；
2. 加工图纸中的完整尺寸标注；
3. 上一平台冻结 CAD 包之外的新增 CAD 细节；
4. 线径；
5. 端子型号；
6. 接插件型号；
7. 每根线的长度；
8. 完整线束拓扑图；
9. 每个支路保险丝最终值；
10. 补光模块后续恢复选型与具体电路；
11. 完整外壳与防护罩；
12. 面向迭代二的复杂扩展结构。

其中三层底板外形、孔位和支撑件 CAD 已由上一平台冻结包承接；其余内容将在后续 BOM、采购清单、接线图、装配照片和 P2-P3 联调中逐步补充。

---

## 15. 上一平台当时待细化项

后续工程阶段需要继续细化：

1. 主电池规格、容量、倍率和接口；
2. 两块双路电驱板到货后的接口、接线和温升验证；
3. 电机型号与编码器参数到货复核；
4. 三层底板到货后的孔位、板面平整度、毛刺和装配兼容性验收；
5. 支撑柱、螺丝、垫片和线束固定件的实物组合；
6. 计算支路、传感器/控制支路和 Mid360 独立 12V DC-DC 的安装固定与温升验证；
7. 后续恢复补光时 D435 与补光模块相对位置；
8. Orin NX、H60、D435、Mid360 和急停按钮的装配后维护可达性；
9. 2.4G USB 接收器固定方式与抗松脱方案；
10. 更细的走线分区图；
11. 正式接线图；
12. 装配照片索引。

---

## 16. 当前结论

项目0迭代一硬件架构已形成可执行的数字重建基线，被动结构件已委托加工；但尚未完成收货、试装、实物验收，也未形成上电或运动准入。

当前结论如下：

1. 项目0在 P1 阶段正式维护 `docs/02_architecture/hardware_architecture.md` 作为硬件架构基线文档。
2. 整车采用四轮差速底盘；车体由用户重新设计，旧三层 CAD 仅作历史。
3. 主计算平台为 Orin NX，底层控制平台为 OpenCTR H60 V3.7。
4. 整车采用单主电池统一供能。
5. 主开关后形成 H60、Orin、Mid360 三条独立主负载支路，并分别设置支路保护。
6. 当前不设置独立急停按钮、继电器、线圈支路或 Orin 急停反馈 GPIO；主开关用于人工整车断电，不称急停。
7. H60 集成四路电驱并驱动四个 MC520P56 电机。
8. 四个电机编码器反馈进入 H60；计数语义和 CPR 重新标定。
9. H60 PC0 采 VIN；首版不装 ACS712，当前没有车载电流采样。
10. H60 与 Orin NX 通过受保护、掉电不反灌的 UART 双向通信。
11. Mid360 和 D435 接入 Orin NX。
12. 2.4G USB 接收器作为 Orin NX 的 USB 外设接入。
13. 补光模块当前 P1.3 采购批次暂缓，架构保留后续弱光视觉支撑扩展可能。
14. H60 默认 DISARMED、Orin 显式 ARM、通信超时、IWDG 和故障撤 PWM 共同约束意外运动；当前车辆没有独立硬件急停。
15. 当前文档用于采购确认、新 CAD、接线和 H0-H8；购买、加工、接线、上电与验收状态以对应记录为准。

---

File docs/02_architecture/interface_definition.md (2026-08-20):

# 1. 文档定位

> **当前实现覆盖（2026-08-20）**：ROS2 topic/service/action 骨架继续有效，底层物理端为 H60。接口实现必须包含显式 ARM/DISARM、STOP、H60 固件/协议版本、四轮原始计数、VIN 与故障状态。当前没有独立急停或急停 GPIO；现有源码中的 `ESTOP`、`TriggerEmergencyStop`、`ResetEmergency` 只属于旧 STM32 迁移子集，H60 迁移时必须废弃或改写，不能作为当前能力。相关字段在 H60 无动力联调与故障注入前不视为冻结或可用于运动。

本文档属于项目0在 P1 阶段的系统架构设计输出物之一，放置在 docs/02_architecture/ 目录下，与 system_architecture.md、compute_comm_architecture.md、power_architecture.md、hardware_architecture.md、software_architecture.md 并列管理。

根据项目文件结构设计，项目0在 docs/02_architecture/ 下单独保留 interface_definition.md，用于继续展开模块间具体接口定义、自定义消息结构与调用关系。

本文档与 software_architecture.md 的边界如下：

* software_architecture.md：回答“为什么这样分包、包之间大概如何交互、主链路和辅助链路如何在软件层面贯通”。
* interface_definition.md：回答“具体有哪些 topic / service / action，它们的名字、数据类型、发布者、订阅者、调用方、返回结构分别是什么”

本文档当前为**P1 接口骨架稿**，服务于迭代一“先跑通主链路、建立统一接口骨架、建立运行管理/记录基础辅助包、保证地图/语义位置表/任务/模式最小成立”的目标。字段随 P2-P6 实现与联调逐步冻结。

当前只形成 P1 接口骨架口径，不代表最终接口冻结；字段级 msg / srv / action 结构仍可在 P2-P5 联调中调整，到 P6 再形成验收冻结版。这是文档成熟度，不是项目发布版本号。

----------------------------------------

# 2. 编写原则

## 2.1 接口分层原则

项目0内部接口分为三类：

* **Topic**：用于持续数据流、状态流、广播型信息，如传感器数据、底盘状态、定位状态、导航状态、系统状态等。
* **Service**：用于快速请求-响应型操作，如模式切换、保存地图、加载地图、查询语义位置、触发自检、STOP/DISARM 等。
* **Action**：用于有执行过程、过程反馈和成功/失败结果的长任务，如点位导航、语义导航任务、长时任务执行反馈等。

## 2.2 接口统一归口原则

凡是跨包通用、且标准消息无法直接表达的结构，统一收口到 `p0_interfaces` 中定义，避免各包私自定义重复数据结构。

典型统一结构包括：

* 底盘控制与状态结构；
* 系统状态结构；
* 安全事件结构；
* 定位质量结构；
* 语义目标结构；
* 任务状态结构。

## 2.3 接口边界原则

接口设计必须服务于分层解耦，而不能破坏分层。典型约束包括：

* `p0_base_bridge` 不直接理解语义任务；
* `p0_navigation` 不直接理解语义目标，只接收可执行的坐标、位姿或路径约束；
* `p0_semantic_nav` 不直接管理地图文件；
* `p0_semantic_nav` 不管理任务生命周期；
* `p0_task_manager` 不直接承担底层路径规划；
* `p0_safety_manager` 集中承担安全仲裁；
* `p0_data_tools` 不反向控制主业务逻辑。

## 2.4 当前版本定位原则

本版本是骨架版接口定义表，因此：

* 允许部分字段写为“待细化 / 后续补充”；
* 允许少量接口名称在 P2-P5 联调中调整；
* 允许为迭代二增强保留预留字段与备注列；
* 但迭代一最小闭环所需接口应尽量先稳定下来；
* 当前形成 P1 骨架口径，P6 验收冻结版将在后续实现与联调中形成。

----------------------------------------

# 3. 命名规范

## 3.1 统一前缀

接口命名统一采用 `/p0/...` 前缀，后续实现时按此落地。

## 3.2 命名风格

建议采用如下风格：

* Topic：`/p0/<domain>/<subdomain>/<name>`
* Service：`/p0/<domain>/<operation>`
* Action：`/p0/<domain>/<task>`

示例：

* `/p0/sensors/lidar/points`
* `/p0/system/set_mode`
* `/p0/navigation/go_to_pose`

## 3.3 类型命名

自定义接口类型统一放入 `p0_interfaces` 包中，命名风格如下：

* msg：`<Name>.msg`
* srv：`<Verb><Name>.srv` 或 `<Name>.srv`
* action：`<Verb><Name>.action`

示例：

* `ChassisCmd.msg`
* `ChassisStatus.msg`
* `SetSystemMode.srv`
* `NavigateToSemantic.action`

----------------------------------------

# 4. 软件包与接口责任映射

| 软件包 | 接口责任 |
| --- | --- |
| `p0_interfaces` | 统一定义项目内部 msg / srv / action |
| `p0_sensor_drivers` | 发布激光雷达、IMU、相机及传感器状态数据 |
| `p0_manual_control` | 将经确认的手柄输入发布为带死人开关的手动底盘意图 |
| `p0_base_bridge` | 接收底盘控制指令，发布底盘反馈、通信状态、运动状态 |
| `p0_mapping` | 消费建图传感器数据，发布建图状态，调用地图保存接口 |
| `p0_localization` | 消费定位传感器数据与地图资源，发布定位状态 |
| `p0_map_manager` | 提供地图保存/加载/当前地图信息，并承接迭代一语义位置表 / 语义位置数据与语义位置查询接口 |
| `p0_navigation` | 接收导航目标，发布导航状态/路径/事件，提供导航 action |
| `p0_semantic_nav` | 接收语义目标输入，通过语义位置查询接口获取位姿或区域，输出导航目标或语义解析结果 |
| `p0_task_manager` | 发起导航任务，维护任务状态，订阅安全事件与导航状态 |
| `p0_safety_manager` | 接收多源状态输入，发布安全事件，必要时触发安全处置接口 |
| `p0_system_manager` | 提供模式切换、自检、故障复位等服务，聚合系统状态 |
| `p0_data_tools` | 订阅关键数据流、状态流、事件流，用于记录与复盘，不反控主逻辑 |

----------------------------------------

# 5. Topic 接口定义表

## 5.1 感知层 Topic

| Topic 名称 | 类型 | 发布方 | 订阅方 | 作用 | 迭代一状态 | 备注 |
| --- | --- | --- | --- | --- | --- | --- |
| `/p0/sensors/lidar/points` | 标准点云消息 | `p0_sensor_drivers` | `p0_localization`, `p0_mapping`, `p0_navigation`, `p0_data_tools` | Mid360 点云主输入 | 必须实现 | 具体消息类型后续细化，建议采用标准点云消息。 |
| `/p0/sensors/imu/data` | 标准 IMU 消息 | `p0_sensor_drivers` | `p0_localization`, `p0_mapping`, `p0_data_tools` | Mid360 内置 IMU 主输入 | 必须实现 | 建议采用标准 IMU 消息。 |
| `/p0/sensors/camera/color` | 标准图像消息 | `p0_sensor_drivers` | `p0_data_tools` | D435 RGB 输入 | 建议实现 | 迭代一先以记录与调试为主，迭代二可增强利用。 |
| `/p0/sensors/camera/depth` | 标准图像/深度消息 | `p0_sensor_drivers` | `p0_data_tools` | D435 深度输入 | 建议实现 | 迭代一先接入，深度利用可后续增强。 |
| `/p0/sensors/status` | `p0_interfaces/SensorStatus` | `p0_sensor_drivers` | `p0_system_manager`, `p0_safety_manager`, `p0_data_tools` | 传感器在线状态、异常状态、基础健康信息 | 接口预留 | 当前类型待补充到 `p0_interfaces`。依据传感器管理与状态可观测预留需求设置。 |

## 5.2 底盘与执行层 Topic

| Topic 名称 | 类型 | 发布方 | 订阅方 | 作用 | 迭代一状态 | 备注 |
| --- | --- | --- | --- | --- | --- | --- |
| `/p0/manual/cmd_vel` | `p0_interfaces/ChassisCmd` | `p0_manual_control` | `p0_safety_manager` | 带死人开关的手动运动意图 | 旧平台无动力复验通过 | Flydigi 映射为 `axis 1 / axis 2 / button 6`；无线心跳超时时 `active=false`。 |
| `/p0/navigation/cmd_vel` | `p0_interfaces/ChassisCmd` | `p0_navigation` | `p0_safety_manager` | 导航产生的自动运动意图 | 接口已落地，导航未接入 | 旧骨架默认 `autonomy_enabled=false`。 |
| `/p0/base/cmd_vel` | `p0_interfaces/ChassisCmd` | 运行仲裁节点（现有迁移包名为 `p0_safety_manager`） | `p0_base_bridge` | 经通信、超时、故障、STOP/DISARM 和手动优先仲裁的唯一最终底盘指令 | 旧 STM32 桥已实现；H60 迁移待完成 | H60 桥必须按新协议验证连续差速、STOP 与显式 ARM/DISARM，不能继承旧实现结论。 |
| `/p0/base/status` | `p0_interfaces/ChassisStatus` | `p0_base_bridge` | `p0_navigation`, `p0_localization`, `p0_system_manager`, 运行仲裁节点, `p0_data_tools` | 底盘反馈、通信、状态机、原始/归一化编码器、逐轮累计转数、VIN 与故障 | 旧 STM32 子集实测；H60 四轮待重建 | 旧 `ESTOP` 字段和解绕逻辑保留为软件历史。H60 版本必须重新确认原始计数宽度、方向、每轮 CPR、故障码、VIN 和会话状态后再冻结字段语义。 |
| `/p0/base/odom` | 标准里程计消息 | `p0_base_bridge` | `p0_localization`, `p0_navigation`, `p0_data_tools` | 底盘里程计输出 | 必须实现 | 消息类型后续细化，建议使用标准 odom 消息。 |
| `/p0/base/event` | `p0_interfaces/BaseEvent` | `p0_base_bridge` | `p0_safety_manager`, `p0_system_manager`, `p0_data_tools` | 底盘通信异常、超时、控制模式变化等事件 | 接口预留 | P1 骨架稿保留。 |

## 5.3 建图与定位层 Topic

| Topic 名称 | 类型 | 发布方 | 订阅方 | 作用 | 迭代一状态 | 备注 |
| --- | --- | --- | --- | --- | --- | --- |
| `/p0/mapping/status` | `p0_interfaces/MappingStatus` | `p0_mapping` | `p0_system_manager`, `p0_data_tools` | 建图状态 | 建议实现 | 已在建议版接口中出现。 |
| `/p0/localization/status` | `p0_interfaces/LocalizationStatus` | `p0_localization` | `p0_system_manager`, `p0_navigation`, `p0_safety_manager`, `p0_data_tools` | 定位质量状态（Good / Degraded / Lost） | 必须实现 | 已在初始接口清单中给出骨架。 |
| `/p0/localization/pose` | 标准位姿消息 | `p0_localization` | `p0_navigation`, `p0_data_tools` | 当前机器人位姿输出 | 必须实现 | 消息类型后续细化。 |
| `/p0/map/current_info` | `p0_interfaces/MapInfo` | `p0_map_manager` | `p0_localization`, `p0_navigation`, `p0_system_manager` | 当前运行地图信息 | 建议实现 | 已在建议版接口中出现。 |

## 5.4 导航层 Topic

| Topic 名称 | 类型 | 发布方 | 订阅方 | 作用 | 迭代一状态 | 备注 |
| --- | --- | --- | --- | --- | --- | --- |
| `/p0/navigation/goal` | 标准位姿目标或自定义目标 | `p0_semantic_nav`, `p0_task_manager` | `p0_navigation` | 导航目标输入 | 必须实现 | 已在建议版接口中出现。 |
| `/p0/navigation/status` | `p0_interfaces/NavigationStatus` | `p0_navigation` | `p0_task_manager`, `p0_safety_manager`, `p0_system_manager`, `p0_data_tools` | 导航执行状态 | 必须实现 | 已在建议版接口中出现。 |
| `/p0/navigation/path` | 标准路径消息 | `p0_navigation` | `p0_data_tools`, 调试工具 | 当前规划路径 | 建议实现 | 便于调试与记录。 |
| `/p0/navigation/event` | `p0_interfaces/NavigationEvent` | `p0_navigation` | `p0_task_manager`, `p0_safety_manager`, `p0_data_tools` | 导航异常、重规划、到达等事件 | 建议实现 | 已在建议版接口中出现。 |

## 5.5 语义与任务层 Topic

| Topic 名称 | 类型 | 发布方 | 订阅方 | 作用 | 迭代一状态 | 备注 |
| --- | --- | --- | --- | --- | --- | --- |
| `/p0/semantic/input` | `p0_interfaces/SemanticGoal` | 外部输入适配节点 / 上层调用方 | `p0_semantic_nav` | 语义目标输入 | 必须实现 | 已在建议版接口中出现。 |
| `/p0/semantic/result` | `p0_interfaces/SemanticResult` | `p0_semantic_nav` | `p0_task_manager`, `p0_data_tools` | 语义解析结果 | 建议实现 | 已在建议版接口中出现。 |
| `/p0/task/state` | `p0_interfaces/TaskState` | `p0_task_manager` | `p0_system_manager`, `p0_data_tools` | 任务状态广播 | 建议实现 | 建议纳入统一任务状态结构。 |

## 5.6 安全与系统管理层 Topic

| Topic 名称 | 类型 | 发布方 | 订阅方 | 作用 | 迭代一状态 | 备注 |
| --- | --- | --- | --- | --- | --- | --- |
| `/p0/safety/event` | `p0_interfaces/SafetyEvent` | `p0_safety_manager` | `p0_task_manager`, `p0_system_manager`, `p0_data_tools` | 安全事件广播 | 必须实现 | 已在初始接口清单中给出骨架。 |
| `/p0/system/status` | `p0_interfaces/SystemStatus` | `p0_system_manager` | 全局关键模块、`p0_data_tools` | 当前系统模式、模块在线状态、基础系统状态 | 必须实现 | 已在初始接口清单中给出骨架。 |
| `/p0/system/heartbeat` | `p0_interfaces/SystemHeartbeat` | `p0_system_manager` | `p0_data_tools`, 监控工具 | 系统周期心跳与存活观测 | 接口预留 | P1 骨架稿预留，便于后续状态可观测增强。 |

----------------------------------------

# 6. Service 接口定义表

## 6.1 地图与语义服务

| Service 名称 | 类型 | 服务方 | 调用方 | 作用 | 迭代一状态 | 备注 |
| --- | --- | --- | --- | --- | --- | --- |
| `/p0/map/save` | `p0_interfaces/SaveMap` | `p0_map_manager` | `p0_mapping`, 运维入口 | 保存当前地图 | 建议实现 | 软件架构指出建图通过请求响应型接口与地图管理协作完成地图保存。 |
| `/p0/map/load` | `p0_interfaces/LoadMap` | `p0_map_manager` | `p0_localization`, `p0_system_manager` | 加载指定地图 | 必须实现 | 软件架构指出地图管理向定位提供地图加载资源。 |
| `/p0/map/query_semantic_pose` | `p0_interfaces/QuerySemanticPose` | `p0_map_manager` | `p0_semantic_nav` | 查询语义位置对应空间目标 | 必须实现 | P1 骨架口径采用 `QuerySemanticPose.srv`，`GetSemanticPose.srv` 仅作为历史备选命名待淘汰，不代表 P6 最终冻结。 |

## 6.2 系统管理服务

| Service 名称 | 类型 | 服务方 | 调用方 | 作用 | 迭代一状态 | 备注 |
| --- | --- | --- | --- | --- | --- | --- |
| `/p0/system/set_mode` | `p0_interfaces/SetSystemMode` | `p0_system_manager` | `p0_task_manager`, 运维入口 | 切换系统模式 | 必须实现 | 已在初始接口清单与建议版接口中出现。 |
| `/p0/system/self_check` | `p0_interfaces/RunSelfCheck` | `p0_system_manager` | 运维入口、`p0_bringup` | 触发自检 | 建议实现 | 已在建议版接口中出现。 |
| `/p0/system/reset_fault` | `p0_interfaces/ResetFault` | `p0_system_manager` | 运维入口 | 清除可恢复故障状态 | 接口预留 | 已在建议版接口中出现。 |

## 6.3 停止、失能与故障锁止服务

| Service 名称 | 类型 | 服务方 | 调用方 | 作用 | 迭代一状态 | 备注 |
| --- | --- | --- | --- | --- | --- | --- |
| `/p0/motion/stop` | 待新增 `p0_interfaces/StopMotion` | 运行仲裁节点 | 运维入口、`p0_system_manager` | 请求 STOP/DISARM 并清除活动运动意图 | H60 迁移必须实现 | 软件停车接口；H60 本地超时与故障撤 PWM 仍须独立成立，当前车辆没有独立硬件急停。 |
| `/p0/motion/clear_lock` | 待新增 `p0_interfaces/ClearMotionLock` | 运行仲裁节点 | 运维入口 | 清除可恢复的软件故障锁止 | H60 迁移必须实现 | 清除后仍须输入回中、状态检查和新的显式 ARM，不恢复旧指令。 |

## 6.4 底盘桥接服务

| Service 名称 | 类型 | 服务方 | 调用方 | 作用 | 迭代一状态 | 备注 |
| --- | --- | --- | --- | --- | --- | --- |
| `/p0/base/reset_bridge` | `p0_interfaces/ResetBridge` | `p0_base_bridge` | `p0_system_manager` | 重新初始化底盘桥接 | 建议实现 | 已在建议版接口中出现。 |
| `/p0/base/set_control_mode` | `p0_interfaces/SetBaseMode` | `p0_base_bridge` | `p0_task_manager`, `p0_system_manager` | 切换底盘控制模式 | 建议实现 | 已在建议版接口中出现。 |

----------------------------------------

# 7. Action 接口定义表

## 7.1 导航 Action

| Action 名称 | 类型 | 服务方 | 调用方 | 作用 | 迭代一状态 | 备注 |
| --- | --- | --- | --- | --- | --- | --- |
| `/p0/navigation/go_to_pose` | 标准导航动作或封装动作 | `p0_navigation` | `p0_task_manager` | 执行点位导航 | 必须实现 | 已在建议版接口中出现。 |
| `/p0/navigation/follow_waypoints` | 标准导航动作或封装动作 | `p0_navigation` | `p0_task_manager` | 执行多点位导航 | 接口预留 | 已在建议版接口中出现片段，迭代一非必须。 |
| `/p0/navigation/navigate_to_semantic` | `p0_interfaces/NavigateToSemantic` | `p0_task_manager`（P1 骨架倾向） | 上层任务调用方 | 语义导航任务编排 | 接口预留 | P1 骨架倾向由 `p0_task_manager` 作为任务编排方，调用 `p0_semantic_nav` 完成语义目标解析，再调用 `p0_navigation` 执行导航；不表示 `p0_navigation` 理解语义，最终归属仍待 P2-P5 联调确认。 |

## 7.2 任务 Action

| Action 名称 | 类型 | 服务方 | 调用方 | 作用 | 迭代一状态 | 备注 |
| --- | --- | --- | --- | --- | --- | --- |
| `/p0/task/execute` | `p0_interfaces/ExecuteTask` | `p0_task_manager` | 上层任务入口 | 执行单步或多步任务 | 接口预留 | 迭代一先保证顺序任务可成立，复杂任务表达后续增强。 |

----------------------------------------

# 8. p0_interfaces 自定义类型骨架

根据架构约束，凡是跨包通用且标准消息无法直接表达的结构，统一放入 `p0_interfaces`。

## 8.1 Message 清单（骨架版）

| 文件名 | 作用 | 当前状态 |
| --- | --- | --- |
| `ChassisCmd.msg` | 上位机 → 底盘：时间戳、线 / 角速度、来源、活动与序列号 | 旧平台已落地 P2 子集 |
| `ChassisStatus.msg` | 底盘 → 上位机：通信、状态机、故障、VIN 和原始/归一化编码器 | 旧字段已落地；H60 语义待迁移 |
| `SystemStatus.msg` | 系统管理：当前模式、各模块在线状态 | 必须实现 |
| `MotionEvent.msg` | 运行仲裁：停止、失能、故障、接管事件类型、等级、时间戳 | H60 迁移时新增 |
| `LocalizationStatus.msg` | 定位模块：定位质量等级（Good / Degraded / Lost） | 必须实现 |
| `MappingStatus.msg` | 建图状态 | 建议实现 |
| `MapInfo.msg` | 当前地图信息 | 建议实现 |
| `NavigationStatus.msg` | 导航执行状态 | 必须实现 |
| `NavigationEvent.msg` | 导航异常 / 重规划 / 到达等事件 | 建议实现 |
| `SemanticGoal.msg` | 语义目标输入结构 | 必须实现 |
| `SemanticResult.msg` | 语义解析结果结构 | 建议实现 |
| `TaskState.msg` | 任务状态结构 | 建议实现 |
| `SensorStatus.msg` | 传感器状态结构 | 接口预留 |
| `BaseEvent.msg` | 底盘桥接事件结构 | 接口预留 |
| `SystemHeartbeat.msg` | 系统心跳结构 | 接口预留 |

## 8.2 Service 清单（骨架版）

| 文件名 | 作用 | 当前状态 |
| --- | --- | --- |
| `QuerySemanticPose.srv` | 查询语义位置 → 空间位姿 | 必须实现 |
| `GetSemanticPose.srv` | 查询语义位置 → 空间位姿 | 历史备选命名，待淘汰 |
| `SetSystemMode.srv` | 请求切换系统模式 | 必须实现 |
| `TriggerEmergencyStop.srv` | 旧 STM32 软件急停接口 | 已弃用；H60 不得使用 |
| `ResetEmergency.srv` | 旧 STM32 软件急停复位接口 | 已弃用；H60 不得使用 |
| `StopMotion.srv` | 请求 STOP/DISARM 并清除活动运动意图 | H60 迁移时新增 |
| `ClearMotionLock.srv` | 清除可恢复锁止；不自动 ARM | H60 迁移时新增 |
| `LoadMap.srv` | 加载地图 | 必须实现 |
| `RunSelfCheck.srv` | 触发自检 | 建议实现 |
| `ResetFault.srv` | 清除可恢复故障状态 | 接口预留 |
| `ResetBridge.srv` | 重新初始化底盘桥接 | 建议实现 |
| `SetBaseMode.srv` | 切换底盘控制模式 | 建议实现 |

> 注：P1 骨架口径建议采用 `QuerySemanticPose.srv`；`GetSemanticPose.srv` 仅保留为历史备选命名并标注待淘汰。该口径不代表 P6 最终冻结。

## 8.3 Action 清单（骨架版）

| 文件名 | 作用 | 当前状态 |
| --- | --- | --- |
| `NavigateToSemantic.action` | 语义导航任务编排（目标名称 → 语义解析 → 导航执行 → 结果反馈） | 接口预留，P1 骨架倾向由 `p0_task_manager` 编排 |
| `ExecuteTask.action` | 任务执行动作 | 接口预留 |
| `GoToPose.action` | 点位导航封装动作 | 建议实现 |

----------------------------------------

# 9. 迭代一最小闭环必需接口

## 9.1 P2 底盘与基础运动成立

至少应先稳定以下接口：

* `/p0/base/cmd_vel`
* `/p0/base/status`
* `/p0/base/odom`
* `/p0/system/status`
* `/p0/safety/emergency_stop`

## 9.2 P3 感知与建图成立

至少应补齐以下接口：

* `/p0/sensors/lidar/points`
* `/p0/sensors/imu/data`
* `/p0/mapping/status`
* `/p0/map/save`
* `/p0/system/self_check`

## 9.3 P4 定位与导航成立

至少应补齐以下接口：

* `/p0/localization/pose`
* `/p0/localization/status`
* `/p0/map/load`
* `/p0/navigation/goal`
* `/p0/navigation/status`
* `/p0/navigation/go_to_pose`

## 9.4 P5 语义导航与任务调度成立

至少应补齐以下接口：

* `/p0/map/query_semantic_pose`
* `/p0/semantic/input`
* `/p0/semantic/result`
* `/p0/task/state`
* `NavigateToSemantic.action`

----------------------------------------

# 10. 接口预留项

根据迭代一“接口预留”原则，以下能力当前可不要求完整实现，但应保留接口扩展空间：

* 传感器统一状态管理接口；
* 通信状态可观测与扩展接口；
* 电源管理 / 电量监测 / 告警 / 保护相关接口；
* 补光接入与控制接口；
* 部署迁移 / 配置管理辅助接口；
* 新传感器 / 新功能模块 / 迭代二增强能力接入接口。

建议在后续版本逐步考虑补充：

* `/p0/power/status`
* `/p0/lighting/control`
* `/p0/comm/status`
* `/p0/system/version_info`

----------------------------------------

# 11. 待统一与待确认项

以下内容形成 P1 骨架口径，但仍不是 P6 最终冻结：

1. 语义位置查询服务在迭代一基线中由 `p0_map_manager` 提供、由 `p0_semantic_nav` 调用；P1 骨架口径采用 `QuerySemanticPose.srv`，`GetSemanticPose.srv` 标注为历史备选命名 / 待淘汰；
2. `TriggerEmergencyStop.srv` 与 `ResetEmergency.srv` 只保留为旧 STM32 源码历史；H60 迁移采用 STOP/DISARM 与可恢复故障锁止语义，目标接口为 `StopMotion.srv` 与 `ClearMotionLock.srv`；包名与最终字段在 P2 实现时冻结；
3. `/p0/navigation/go_to_pose` 是否直接采用 Nav2 标准动作，还是由 `p0_navigation` 再封装一层；
4. `NavigateToSemantic.action` 的 P1 骨架倾向由 `p0_task_manager` 作为任务编排方，调用 `p0_semantic_nav` 与 `p0_navigation`；最终 action 命名空间、服务方归属和字段结构仍待 P2-P5 联调确认；
5. 部分 Topic 的标准消息类型选型与最终字段（如 odom、pose、path 等）在 P2-P4 联调中进一步确认。
6. 所有字段级 msg / srv / action 结构仍可在 P2-P5 联调中调整，P6 再形成验收冻结版正式接口清单。

----------------------------------------

# 12. 维护规则

## 12.1 版本管理

本文件采用增量维护方式：

* P1 骨架稿：建立统一接口骨架；
* P2-P3 联调稿：补齐底盘、建图、定位关键接口；
* P4-P5 导航任务稿：补齐语义导航与任务调度接口；
* P6 验收冻结版：冻结迭代一正式接口清单。

## 12.2 修改原则

后续修改应遵循：

* 优先新增字段，避免随意破坏既有接口；
* 优先保持命名统一与前向兼容；
* 自定义结构优先沉淀到 `p0_interfaces`；
* 字段级接口变更或 P6 验收冻结前的正式接口调整应对应 CHANGELOG 条目，并与项目版本路线图对齐；仅标注 P1 骨架状态和待确认项时，可按对应 CR 留痕。

## 12.3 与后续文档协同

本文件后续应与以下文档联动更新：

* 后续各模块详细设计文档；
* `docs/04_deployment/` 部署与运行文档；
* `docs/06_testing/` 测试计划、验收标准与测试记录；
* `hardware/wiring/` 接线图与相关物理接口说明；

----------------------------------------

# 13. 附：本版最小自定义接口骨架示例

> 旧平台工程曾落地底盘控制所需子集，但对应源码未在当前公开快照发布；其余类型仍按骨架状态逐步实现。

## 13.1 ChassisCmd.msg（旧平台已落地）

```text
std_msgs/Header header
float32 linear_x_mps
float32 angular_z_radps
string source
bool active
uint32 sequence
```

## 13.2 ChassisStatus.msg（旧平台修正计数语义）

```text
# 旧平台已落地时间戳、通信 / ESTOP / 控制状态，
# LF/LR/RF/RR 原始与归一化计数、接收年龄和最后事件。
# 后续旧平台迭代增加 encoder_calibrated 与四轮累计 revolutions。
# raw_encoder_* 保留为 STM32 瞬时原始值；
# encoder_* 改为经 16-bit 解绕和方向归一化的连续计数，
# revolutions 由连续计数换算。STM32 重启标记会重置解绕基线。
# 轮速、轮径 / 轮距、odom、电压和故障码待后续实测接入。
```

## 13.3 SystemStatus.msg（占位）

```text
# TODO: 当前模式、模块在线状态、系统故障等级、时间戳等字段后续细化
```

## 13.4 SafetyEvent.msg（占位）

```text
# TODO: 事件类型、等级、来源模块、时间戳、描述等字段后续细化
```

## 13.5 LocalizationStatus.msg（占位）

```text
# TODO: 定位质量枚举（Good / Degraded / Lost）、时间戳、附加说明
```

## 13.6 SetSystemMode.srv（占位）

```text
# Request:
#   target_mode
# Response:
#   success
#   message
```

## 13.7 TriggerEmergencyStop.srv（旧平台已落地）

```text
string reason
---
bool success
string message
```

## 13.8 ResetEmergency.srv（旧平台已落地）

```text
string reason
---
bool success
string message
```

## 13.9 NavigateToSemantic.action（占位）

```text
# Goal:
#   semantic_name
# Feedback:
#   progress / current_state
# Result:
#   success / fail_reason
```

----------------------------------------

# 14. 总结

本文档作为 `interface_definition.md` 的 P1 骨架稿，已经在软件架构给出的接口组织原则、架构级接口关系、建议版话题/服务/动作接口与 `p0_interfaces` 初始接口清单基础上，整理出面向迭代一最小闭环的 P1 接口定义表骨架，用于支撑后续 P2-P6 的模块设计、实现、联调、测试与验收；字段级结构和最终接口清单以 P2-P5 联调结果与 P6 验收冻结版为准。

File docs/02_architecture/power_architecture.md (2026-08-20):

# Power Architecture

# 项目0 迭代一电源架构

> **当前实现覆盖（2026-08-20）**：现行电源树为 `3S -> 25A 主保险 -> 外置主开关 -> 带支路保护分配`，再分 H60、Orin、Mid360 三条主负载支路。当前无独立急停、继电器、线圈支路或车载电流采样；只有 H60 PC0 VIN 电压采样。精确接线以 `hardware/wiring/h60_power_wiring_v0_2.md` 为准。本文第 3–17 节只作上一 STM32/JGB 小车历史。

## 1. 文档定位

本文档属于 P1 阶段系统架构设计输出之一，用于明确项目0迭代一的电源路径、电压转换、保护和电压监测，为后续硬件接线、BOM、采购、P2 机械与电气组装、P6 集成验收提供依据。

P1 已明确要求输出电源架构，其核心内容包括：**电池→各设备供电路径、电压转换方案、电源保护**。

建议文件放置位置为 `docs/02_architecture/power_architecture.md`，与系统总架构、计算通信架构、硬件架构、软件架构并列管理。

---

## 2. 架构目标

迭代一电源架构的目标不是一次性做成复杂电源系统，而是支撑当前单车闭环，并满足后续调试与验收的基础需求。

本电源架构应满足以下目标：

1. 为四轮差速底盘、Orin NX、H60、Mid360、D435 与人工接管输入链路提供清晰供电关系。
2. 通过主保险、三条支路保护、正确线径/端子和主开关人工断电，约束短路、过热与异常运动处置风险；主开关不称为急停。
3. 通过 H60 PC0 VIN ADC 支撑 H60 上电期间的电压状态检查；当前不具备车载电流采样或 H60 失电后的持续电池观测。
4. 保持架构简单、可维护、适合单人开发，不为了未来扩展而在迭代一引入过重电源复杂度。

---

## 3. 上一 STM32/JGB 平台历史展开（非当前实现）

> 本文第 3–17 节保留 P1 与上一实车平台形成的电源架构正文，用于追溯旧 STM32、双 WSDC、JGB、CTRL-001、ACS712、急停/继电器和六路保险盒设计。它们不再定义当前接线、采购或验收。当前实现只以页首覆盖说明、第 18 节、`p2_h60_rebuild_baseline.md` 和 `hardware/wiring/h60_power_wiring_v0_2.md` 为准。

### 3.1 当时的电源架构设计约束

#### 3.1.1 系统计算与执行边界

项目0采用“**单主计算平台 + 单底层控制平台 + 外设接入**”结构，Orin NX 是唯一主计算与主控平台，STM32 是唯一底层执行控制平台。

Orin NX 承担感知接入、定位建图、导航避障、语义导航、任务调度、安全监测、系统管理与数据记录等主业务，因此其供电必须作为高优先级稳定支路单独考虑。

STM32 承担电机驱动、编码器读取、里程计初步计算、底盘安全保护、接收上位机速度指令、上传底层状态等职责，因此它与电机驱动链路、电量监测链路直接相关。

#### 3.1.2 传感器与补光约束

迭代一关键传感器包括 Mid360 与 D435，其中 Mid360 是 FAST-LIO2 的主感知输入来源，D435 在迭代一中作为前向辅助感知、调试与记录数据源，不参与 FAST-LIO2 正式融合。

系统保留后续补光支撑能力；SENS-004 / SENS-005 / SENS-006 在当前批次暂缓，不作为当前必购、必装、必测硬件。

#### 3.1.3 安全与管理约束

硬件急停按钮通过**纯硬件电路直接切断电机驱动供电**，不经过软件链路。

系统管理能力要求在启动时检查电量或供电状态是否满足运行条件，并在运行过程中监控电源状态。

P6 系统集成与验收要求补全**电源监控与低电量保护**能力，并在异常场景联调中覆盖低电量场景。

---

## 4. 电源架构总体原则

### 4.1 主电池统一供能
整车采用单主电池作为统一能源入口，再分支给动力、计算、传感器/控制、Mid360 独立感知供电等子系统供电，以保持供电关系清晰。

### 4.2 动力与计算分离
动力支路与计算支路必须电气分离，避免电机负载波动直接影响 Orin NX 主计算平台稳定性。

### 4.3 急停只切动力支路
急停仅切断电机驱动供电，不切断 Orin NX、STM32、Mid360、D435 等计算、控制、感知支路，以保留状态监控、故障记录、人工诊断和优雅关闭能力。

### 4.4 低压侧按职责分层
低压侧至少拆分为：
- 计算支路
- 传感器/控制支路
- Mid360 独立 12V 感知供电支路

而不是把所有低压设备挂在同一低压模块下，以提高问题隔离性、维护性与可观测性。

### 4.5 迭代一先做基础监测与保护
迭代一先实现：
- 电池电压监测
- 低电量告警
- 低电量保护触发接口
- 供电关系清晰化

更高级的电量估算、剩余续航预测、复杂功耗优化不纳入当前阶段。

---

## 5. 供电对象清单

本架构覆盖以下主要供电对象：

### 5.1 动力侧
- 四轮底盘电机驱动板
- 四个 JGB-520 电机（由驱动板输出到电机）

### 5.2 计算侧
- Jetson Orin NX 16GB
- Intel RealSense D435（通过 Orin NX USB 口接入并供电）
- 2.4G USB 接收器（通过 Orin NX USB 口接入并供电，服务人工接管输入）

### 5.3 传感器/控制侧
- STM32 控制板
- 低压采样与底层状态输入
- 预留小信号接口与后续补光控制扩展余量（当前 P1.3 采购批次暂缓）

### 5.4 Mid360 独立感知供电侧
- Livox Mid360

### 5.5 监测侧
- 主电池电压采样链路（建议由 STM32 负责采样与上报）

---

## 6. 电源分层与供电路径

## 6.1 总体拓扑

整车电源拓扑定义为：

**主电池 → 主电源入口 → 分为动力支路 / 计算支路 / 传感器控制支路 / Mid360 独立 12V 感知供电支路 → 各设备**。

其中，动力支路与低压支路并联分出；低压支路内部再拆分为计算支路、传感器/控制支路和 Mid360 独立 12V 感知供电支路。

---

## 7. 动力支路设计

### 7.1 动力支路路径

动力支路采用如下路径：

**主电池 → 主保护器件/总开关 → 硬件急停回路 → 电机驱动板 → 四个电机**。

### 7.2 动力支路电压策略

迭代一采用 **3S 主电池直接供给电机驱动板** 的方案，不在电池与驱动板之间额外引入一层大功率中间稳压级。
该方案符合迭代一“先做成、先闭环、先保证稳定运动和可靠停车”的策略，也符合 STM32 通过 PWM 驱动电机驱动板完成底盘运动控制的实现路径。

### 7.3 动力支路安全边界

动力支路是硬件急停的直接作用对象。
按下急停按钮后，应立即切断电机驱动板供电，从而实现电机失能与整车停止。

此外，底盘安全保护还包括 STM32 固件中的速度限幅与通信超时自动停车，这是硬件急停之外的第二层执行安全保障。

---

## 8. 计算支路设计

### 8.1 计算支路路径

计算支路采用如下路径：

**主电池 → 独立 DC-DC 稳压模块 → Orin NX**。

### 8.2 计算支路设计原则

Orin NX 是系统唯一主计算与主控平台，承担感知、定位、导航、任务、安全、系统管理、数据记录等全部上层关键能力，因此其供电应被视为**高优先级稳定支路**。

该支路应满足：
- 与动力支路电气隔离
- 不受急停切断
- 供电稳定，优先保证主计算平台不断电
- 能支撑系统监控、日志记录、模式切换与优雅关闭流程。

### 8.3 设计意图

保留 Orin NX 持续供电，能够在急停、通信中断、导航失败、低电量等异常场景下继续记录状态、输出异常等级、执行系统管理策略，并为 P6 的全链路联调与验收提供支撑。

该支路只服务 Orin NX，不作为 Mid360 供电来源。

---

## 9. 低压感知与控制支路设计

### 9.1 Mid360 独立感知供电支路

Mid360 独立感知供电支路采用如下路径：

**主电池 → 分路保险盒 → Mid360 支路保险 → 独立 12V 升降压 DC-DC → Mid360**。

该支路只承载 Livox Mid360 的 12V 稳压供电。Mid360 的以太网数据链路仍接入 Orin NX 载板 RJ45。

Mid360 是 FAST-LIO2 主感知输入，供电稳定性直接影响建图和定位主链路。虽然 Mid360 允许 9-27V DC 输入，但正式装车不采用主电池裸直供，也不与 Orin NX 计算支路 DC-DC 或 STM32 传感器/控制支路 DC-DC 共用。

该支路不受硬件急停切断。

### 9.2 传感器/控制支路路径

传感器/控制支路采用如下路径：

**上一平台历史：主电池 → 独立 DC-DC 稳压模块（CTRL-001）→ STM32 / 主电池电压采样 / ACS712 信号侧 / 急停与电驱状态输入 / 预留小信号接口**。

### 9.3 传感器/控制支路职责

该支路职责与边界如下：

- STM32：底层控制、底层状态上传、电量采样上报、接收 Orin NX 经底盘桥接与 UART 下发的人工接管速度指令。
- D435 不作为传感器/控制支路负载，通过 Orin NX USB 口接入并供电，CTRL-001 不承担 D435 供电。
- 补光模块已暂缓当前批次，CTRL-001 当前不为补光灯体供电，仅保留后续补光控制小信号扩展余量。

人工接管输入入口为 2.4G USB 接收器，通过 Orin NX USB 口接入并供电，由 Orin NX 上的 teleop / 手动控制节点生成 `cmd_vel`，再经底盘桥接与 UART 链路下发到 STM32；它不作为传感器/控制支路 DC-DC 的独立负载。

### 9.4 不与 Orin / Mid360 共用单模块的原因

尽管这些设备都属于低压侧，但传感器/控制支路与计算支路、Mid360 独立感知供电支路分开，更符合职责边界清晰、故障隔离、调试维护简单的工程原则，也更适合单人开发中的快速定位问题。

---

## 10. 补光预留设计

### 10.1 功能定位

补光能力保留为后续弱光 / 夜间场景扩展能力。SENS-004 补光模块、SENS-005 补光控制模块、SENS-006 补光模块安装支架在当前批次暂缓，不作为当前必购、必装、必测硬件。

### 10.2 支路关系

当前 P1.3 的传感器/控制支路负载不含补光灯体，CTRL-001 不为补光灯体供电。电源架构仅保留后续补光控制小信号扩展余量，具体灯体供电与控制器件需在恢复补光选型时另行确认。

### 10.3 后续恢复条件

后续若暗光实测表明 D435 RGB 图像无法满足识别、调试或记录需求，可重新开启补光模块选型，并在对应 CR / DEC 约束下确认：
- 补光灯体供电边界
- 补光控制器件
- 安装位置与散热约束
- 弱光场景测试要求

在未重新开启选型前，补光不作为当前 P1.3 必做项。

---

## 11. 电量监测与低电量保护设计

### 11.1 电量监测定位

系统必须具备：
- 电池电量监测能力
- 低电量告警能力
- 低电量保护策略
- 供电路径清晰管理能力

启动时，系统管理链路还应检查电量或供电状态是否满足运行条件。

### 11.2 监测实现边界

迭代一建议采用**主电池电压监测**作为基础实现路径，由 STM32 负责采样，再通过 UART 上报给 Orin NX，由系统管理与安全管理逻辑消费该状态。

这符合：
- STM32 已承担底层状态上传职责
- Orin NX 统一承担系统管理、运行监控与数据记录职责

### 11.3 低电量处理策略

迭代一阶段建议定义至少三级电量状态：

1. **正常**
2. **低电量告警**
3. **低电量保护**

低电量保护策略至少应支持：
- 禁止进入新的自主任务
- 触发系统告警
- 必要时触发安全停车/受限运行

这与系统管理能力、异常分级管理能力和 P6 电源监控与低电量保护要求一致。

---

## 12. 急停与供电边界

### 12.1 急停作用范围

硬件急停按钮只切断**电机驱动供电**，不切断：
- Orin NX
- STM32
- Mid360
- D435
- 2.4G USB 接收器（通过 Orin NX USB 口接入并供电）
- 电量监测与日志记录支路

### 12.2 这样设计的原因

该设计满足以下要求：

1. 硬件急停直接作用于最危险的动力执行链路，安全优先级最高。
2. 保留系统管理、自检、状态输出、异常记录和优雅关闭能力，避免“直接断电式关闭”。
3. 符合数据记录链路应覆盖全过程、不参与控制优先级竞争但全程伴随的系统设计原则。
4. 便于 P6 异常场景联调与安全专项测试中的急停响应、异常停车可靠性验证。

---

## 13. 电源保护原则

迭代一电源保护采用边界清晰、可测量、可维护的基础方案。

### 13.1 主入口保护
主电池输出后应设置主保护器件与总开关，作为整车上电入口的第一道保护。

### 13.2 动力侧保护
动力支路应具备：
- 硬件急停切断能力
- STM32 通信超时自动停车
- STM32 速度限幅保护

驱动板若支持过流/过温保护，可作为增强项接入；若硬件能力不足，迭代一不强制复杂实现。

### 13.3 低压侧保护
低压侧至少通过独立稳压模块实现：
- 计算支路保护
- 传感器/控制支路保护

以避免单点低压故障扩散影响全部设备。

---

## 14. 电源架构文字图

```text
主电池(3S)
│
├─ 主电源入口 / 主保护 / 总开关
│
├─ 动力支路
│   └─ 硬件急停回路
│       └─ 电机驱动板
│           └─ 四个驱动电机
│
├─ 计算支路
│   └─ 独立DC-DC稳压
│       └─ Orin NX
│
├─ Mid360 独立感知供电支路
│   └─ 独立12V升降压DC-DC
│       └─ Mid360
│
└─ 传感器/控制支路
    └─ 独立DC-DC稳压
        ├─ STM32
        ├─ 主电池电压采样 / ACS712 信号侧
        └─ 预留小信号接口（后续补光控制扩展）

人工接管输入：
飞智黑武士2手柄 ─→ 2.4G USB 接收器 ─→ Orin NX(USB供电与输入) ─→ teleop/手动控制节点 ─→ cmd_vel ─→ 底盘桥接 ─→ UART ─→ STM32

主电池电压采样：
主电池 ─→ STM32采样 ─→ UART上报 ─→ Orin NX系统管理/安全管理
```

该拓扑符合 P1 对电源架构的定义要求，也与计算通信架构、系统管理能力、安全机制和电源管理能力保持一致。

---

## 15. 与软件/系统管理链路的接口关系

电源架构不是孤立硬件设计，它需服务于软件与系统管理链路。

### 15.1 系统管理链路
Orin NX 上的系统管理链路负责：
- 启停管理
- 状态管理
- 自检
- 配置管理
- 运行监控

因此，电源架构必须向系统管理提供至少以下状态输入：
- 主电池电压状态
- 低电量等级
- 急停状态
- 底层供电相关异常状态

### 15.2 安全链路
安全保障链路由：
- 纯硬件急停
- STM32 底层保护
- Orin NX 上层安全监控

三层构成。

因此电源架构中的急停与低电量保护，应被视为安全链路的一部分，而不只是“硬件供电细节”。

---

## 16. 上一平台当时版本未细化内容

为保持迭代一范围收敛，以下内容在本版架构中暂不定死：

1. 各 DC-DC 的具体输出电压数值与型号
2. 线径、连接器、端子、保险丝规格
3. 驱动板具体型号与最大电流余量
4. 电池 SOC 高精度估算方案
5. 复杂电源滤波、EMI 细节与多级冗余设计
6. 复杂功耗优化与续航预测模型

这些内容应在 BOM、接线图、采购清单和后续电气实现阶段逐步细化，而不在当前版本过度展开。

---

## 17. 上一平台当时待细化项

尽管当前信息已经足够约束电源架构主拓扑，但以下内容仍需在后续工程阶段细化：

1. 主电池与总开关、急停、驱动板的具体物理位置与布线路径
2. 计算支路 DC-DC 规格与安装位置
3. Mid360 独立 12V DC-DC 具体型号与安装位置
4. 传感器/控制支路 DC-DC 规格与安装位置
5. 后续恢复补光时的开关控制器件选型
6. STM32 电压采样分压/隔离方案
7. 急停状态是否同时回传 STM32/Orin 作为软件状态输入
8. 低电量保护阈值在 `system_params.yaml` 中的参数化定义

---

## 18. 当前结论

基于当前已知信息，项目0迭代一电源架构已经可以被**主拓扑层面完全约束并形成正式文档**。

其核心结论为：

1. 采用单主电池统一供能。
2. 主开关后分为 H60、Orin、Mid360 三条独立主负载支路，并分别设置支路保护。
3. H60 支路由 3S 直供；当前不设置独立急停、继电器或线圈支路。
4. Orin NX 使用独立稳压支路。
5. Mid360 使用独立 SENS-009 12V 升降压支路；D435 与 2.4G USB 接收器由 Orin NX USB 接入；两者均不从 H60 取电。
6. 首版由 H60 PC0 VIN ADC 提供 H60 上电期间的电压监测；不装 Keyes/ACS712，功能范围不含 H60 失电后的持续电池遥测或整车电流遥测。
7. 补光能力保留后续弱光场景扩展可能；SENS-004 / SENS-005 / SENS-006 当前 P1.3 采购批次暂缓，不作为当前必购、必装、必测硬件。

该架构服从“先完成真实闭环、再逐步增强”的顺序，并与后续 P2–P6 的执行、感知、系统管理和验收路径保持一致。

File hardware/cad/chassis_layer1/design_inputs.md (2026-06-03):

# 第一层底盘设计输入

状态：草案，待尺寸复核和 CAD 草模验证。

本文记录第一层底盘 CAD v0.1 建模所需的尺寸、孔位、安装关系、避让空间和来源依据。

本文不替代 BOM、采购清单、DEC、架构文档或实物验证记录。若本文参数与 BOM/DEC 中的硬件身份、状态或架构边界冲突，应回到上游事实源处理。

---

## 1. 设计方向

1. 整车目标是在保证安全、散热、维护和线束固定的前提下，尽量减小外形尺寸。
2. 第一层底板承载主要重件和动力相关硬件。
3. 电机安装在第一层底板下方。
4. 电机输出轴采用靠近电机支架底板安装面的安装方式。
5. 第一层底板不是标准矩形，需要为轮胎开窗，使轮胎顶部部分穿过底板。
6. 急停按钮和主电源开关放在第二层尾部两侧。
7. PCB 类硬件不直接贴底板安装，使用垫柱或绝缘支撑件。

---

## 2. 第一层底板初始范围

| 参数 | 数值 | 来源 | 备注 |
|---|---:|---|---|
| 外轮廓长度初值 | 270 mm | 实物试摆估算 | 后续随轮胎窗口、电机支架孔位和硬件布局调整 |
| 外轮廓宽度初值 | 208.4 mm | 左右轮系装配 v0.1 | `175 mm` 轮距 + `33.4 mm` 轮胎宽度；作为不超出轮胎外边的 v0.1 验证基准 |
| 下一轮长度候选 | 优先 290 mm，备选 300 mm | 第一层装配验证 v0.1 / 第二层布局验证入口 | 用于增加前后窄边、角部立柱孔位和板材刚度余量 |
| 板材 | 待定 | 设计待确认 | 需结合重量、刚度、加工方式和成本选择 |
| 板厚 | 待定 | 设计待确认 | 初步倾向 3 mm 级别，最终需结合材料和开窗后刚度确认 |
| 轴距初值 | 180 mm | v0.1 草案 | 前后轮轴中心距，后续随实物装配复核 |
| 轮距初值 | 175 mm | 左右轮系装配 v0.1 | 左右轮轴中心距；由 `173 mm` 极限检查值调整而来，编码器间距目标约 `3.4 mm` |

---

## 3. 通用安装与高度规则

### 3.1 PCB 垫柱规则

PCB 类硬件底部存在焊点，不应直接贴在底板上安装。

| 参数 | 建议/数值 | 来源 | 备注 |
|---|---:|---|---|
| 默认垫柱高度 | 待定，建议 6 mm 起步 | 设计假设 | 若底部焊点较高或下方需要走线，可提高到 8 mm |
| 总安装高度计算 | 垫柱高度 + PCB 底面到最高器件高度 | 设计规则 | 不含底板厚度 |
| 底部避让高度 | 垫柱高度 | 设计规则 | 用于避让焊脚和底部走线 |
| 第二层下挂电驱候选 | 待验证 | 第一层装配验证 v0.1 | 优先验证两块电驱安装在第二层底板下方，以释放第一层中部两侧空间 |

### 3.2 孔位与边距

| 参数 | 建议/数值 | 来源 | 备注 |
|---|---:|---|---|
| PCB 安装孔加工余量 | 按实际螺丝规格放大 0.2 mm 左右 | 设计假设 | 需结合加工方式确认 |
| 孔到板边最小距离 | 待定，建议不小于 6-8 mm | 设计假设 | 电机支架和轮胎窗口附近应更保守 |
| 轮胎窗口边缘余量 | 待定，建议单侧 3-5 mm 起步 | 设计假设 | 需考虑轮胎偏摆、装配误差和联轴器偏心 |

---

## 4. 传动与轮系输入

### 4.1 PWR-MOT-006 轮胎

参考图：`reference_drawings/轮胎.png`

| 参数 | 数值 | 来源 | 备注 |
|---|---:|---|---|
| 轮胎外径 | 85 mm | 商家尺寸图 | 85 mm 天然橡胶轮胎 |
| 轮胎宽度 | 33.4 mm | 商家尺寸图 | 剖面宽度 |
| 轮毂外径 | 57.6 mm | 商家尺寸图 | 剖面图标注 |
| 轮毂内孔 | 4 mm | 商家尺寸图 | 图中标注 `Φ4` |
| 轮胎与联轴器装配后总宽度 | 约 36.04 mm | 实测/补充 | 用于底板窗口宽度和轮距估算 |

### 4.2 PWR-MOT-007 轮毂联轴器

参考图：`reference_drawings/联轴器.webp`

| 参数 | 数值 | 来源 | 备注 |
|---|---:|---|---|
| 类型 | 抱紧式六角联轴器 | 用户补充 | 3/4/5/6 mm 系列 |
| 内径 | 6 mm | 用户补充 | 匹配电机输出轴 |
| 外径 | 20 mm | 商家尺寸图 | 6 mm 版本属于 `Φ20` 外径组 |
| 抱紧高度 h1 | 11 mm | 商家尺寸图 | 3/4/5/6 mm 系列 |
| 轴孔深度 h2 | 11.8 mm | 商家尺寸图 | 6 mm 版本 |
| 锁紧螺丝 | M3 | 商家尺寸图 | 需装配时避让 |

### 4.3 PWR-MOT-005 JGB-520 带编码器减速电机

参考图：`reference_drawings/电机.webp`

| 参数 | 数值 | 来源 | 备注 |
|---|---:|---|---|
| 型号族 | JGB37-520 带编码器 | 商家尺寸图 | BOM 中为 JGB-520 |
| 减速比 | 70 | 用户补充 | 对应 L 尺寸分组需按图确认 |
| 输出轴形式 | D 型轴 | 用户补充 | 影响联轴器锁紧方向 |
| 输出轴直径 | 6 mm | 商家尺寸图/用户补充 | 图中 `D6`，联轴器为 6 mm |
| 输出轴长度 | 15 mm | 商家尺寸图 | 图题 `D6 15MM` |
| 输出轴 D 面长度 | 12 mm | 商家尺寸图 | 图中标注 `12±0.1` |
| 输出轴端部小径段 | 5.5 mm | 商家尺寸图 | 图中标注 `5.5 -0.1` |
| 电机减速箱外径 | 37 mm | 商家尺寸图 | 图中 `Φ37` |
| 电机后端编码器外径 | 32.3 mm | 商家尺寸图 | 图中 `Φ32.3` |
| 编码器线长 | 144 mm | 商家尺寸图 | 用于走线参考 |

### 4.4 PWR-MOT-008 电机安装支架

参考图：`reference_drawings/电机支架.webp`

| 参数 | 数值 | 来源 | 备注 |
|---|---:|---|---|
| 支架类型 | JGB37MM 减速电机固定支架 | 商家尺寸图 | 金属支架 |
| 底部外形 | 40 mm x 42.4 mm | 商家尺寸图 | 底板接触面 |
| 底部厚度 | 3 mm | 商家尺寸图 | 图中标注 |
| 底部安装孔 | 4 x Φ4 mm | 商家尺寸图 | 用于固定到底板下方 |
| 底部安装孔距 | 30 mm x 23.4 mm | 商家尺寸图 | 图中底部孔位 |
| 侧面电机固定孔 | 6 x Φ3.2 mm | 商家尺寸图 | 用于电机法兰安装 |
| 侧面中心开槽宽度 | 13 mm | 商家尺寸图 | 电机输出轴/凸台避让 |
| 支架总高 | 47 mm | 商家尺寸图 | 侧面图标注 |
| 轴心到底板安装面下表面距离 | 约 33.673 mm | 单侧轮系装配 v0.1 | 当前选定支架姿态；用于轮胎缺口和电机离地关系推导 |
| 另一支架姿态轴心距安装面 | 约 19 mm | 用户补充 | 当前不采用 |
| 选定安装方式 | 轴心到底板安装面下表面距离约 33.673 mm | 单侧轮系装配 v0.1 | 目标是窗口较短且电机离地更合理 |

---

## 5. 第一层核心硬件输入

### 5.1 PWR-004 主电池托盘

参考：`hardware/cad/power_tray/design_record.md`

| 参数 | 数值 | 来源 | 备注 |
|---|---:|---|---|
| 托盘外形 | 139.5 mm x 81.7 mm x 18 mm | 电源托盘设计记录 | 用于第一层布局占位 |
| 托盘内腔 | 133.5 mm x 75.7 mm | 电源托盘设计记录 |  |
| 安装孔 | M3 通孔，直径 3.2 mm | 电源托盘设计记录 | 四角安装孔 |
| 安装孔中心距外边 | 8 mm | 电源托盘 README/设计前提 | 用于底板安装孔匹配 |
| 绑带槽 | 30 mm x 4 mm | 电源托盘设计记录 | 底板布局需避让绑带路径 |
| 电池本体尺寸 | 不在本文件重复定义 | 用户补充 | 第一层按托盘外形建模 |

### 5.2 PWR-MOT-004 双路电机驱动板

参考图：`reference_drawings/电驱.png`

| 参数 | 数值 | 来源 | 备注 |
|---|---:|---|---|
| PCB 标称外形 | 50 mm x 50 mm | 商家尺寸图 | 图中标注 |
| 安装孔孔径 | Φ3.2 mm | 商家尺寸图 | 四角孔 |
| 安装孔距 | 45 mm x 45 mm | 商家尺寸图 | 图中标注 |
| 功率接线端子后长边占位 | 58 mm | 用户补充 | 接上螺丝压线端子后，长边由 50 mm 变为约 58 mm |
| 高度 | 约 11.6 mm | 用户补充 | 接线端子顶部到底板底面，不含焊脚、不含垫柱 |
| 垫柱安装 | 是 | 设计规则 | 总高度需加垫柱高度 |
| 数量 | 2 | BOM | 两块双路电驱板 |

### 5.3 WIRE-001 分路保险盒 / 负极汇流排

| 参数 | 数值 | 来源 | 备注 |
|---|---:|---|---|
| 外形尺寸，带保护盖 | 88 mm x 84.2 mm x 36.2 mm | 用户补充 | 用于第一层布局占位 |
| 长边孔距 | 73.7 mm | 用户补充 | 安装孔位 |
| 宽边孔距 | 69.8 mm | 用户补充 | 安装孔位 |
| 维护限制 | 更换保险丝或打开保护盖需要拆第二层底板，并可能拆下保险盒 | 用户补充 | 设计时应尽量保证固定螺丝和线束可维护 |

### 5.4 CTRL-002 STM32 控制板

参考图：`reference_drawings/STM32F407VET6.png`

| 参数 | 数值 | 来源 | 备注 |
|---|---:|---|---|
| 板外形 | 43.40 mm x 66.93 mm | 商家尺寸图 | 核心板 V5.2 |
| 安装孔中心距 | 35.81 mm x 65.28 mm | 商家尺寸图 | 图中标注 |
| 安装孔孔径 | 4.0 mm | 商家尺寸图 | M4 螺丝孔 |
| 板厚 | 1.6 mm | 商家尺寸图 | 图中标注 |
| 排针规格 | 2.54 mm | 商家尺寸图 | 用于插线高度和侧向空间参考 |
| 是否第一层安装 | 待定 | 布局待确认 | 可放第一层，也可上第二层 |

---

## 6. DC-DC 与电源模块输入

### 6.1 COMP-001 Orin NX 独立 DC-DC 稳压电源模块

参考图：`reference_drawings/Orin NX DCDC.png`

| 参数 | 数值 | 来源 | 备注 |
|---|---:|---|---|
| 实物识别 | 绿色 PCB | 用户纠正 | 不得与黑色 PCB 控制支路 DC-DC 混淆 |
| PCB 外形 | 60.07 mm x 34.93 mm | 商家尺寸图 | 用户补充接端子后长度见下 |
| 安装孔距 | 46.63 mm x 27.28 mm | 商家尺寸图 | 图中标注 |
| 安装孔圆角/孔半径标注 | R 1.84 mm | 商家尺寸图 | 可按 M3 孔或实测确认 |
| 接线端子后长度 | 71.3 mm | 用户补充 | 少了一个螺丝压线端子时的修正占位 |
| 高度 | 约 17 mm | 用户补充 | 不含垫柱 |
| 垫柱安装 | 是 | 设计规则 | 总高度需加垫柱高度 |
| 是否第一层安装 | 待定 | 布局待确认 | 可根据空间和走线放第一层或第二层 |

### 6.2 CTRL-001 控制支路 DC-DC 电源模块

参考图：`reference_drawings/控制支路DCDC.png`

| 参数 | 数值 | 来源 | 备注 |
|---|---:|---|---|
| 实物识别 | 黑色 PCB | 用户纠正 | 6A 款 |
| PCB 外形 | 60 mm x 30 mm | 商家尺寸图 | 图中标注 |
| 安装孔距 | 53 mm x 24 mm | 商家尺寸图 | 图中标注 |
| 安装孔孔径 | Φ3.2 mm | 商家尺寸图 | 四角孔 |
| 板子高度 | 14 mm | 商家尺寸图/用户补充 | 6A 款；不含垫柱 |
| 垫柱安装 | 是 | 设计规则 | 总高度需加垫柱高度 |
| 是否第一层安装 | 待定 | 布局待确认 | 可根据空间和走线放第一层或第二层 |

### 6.3 SENS-009 Mid360 独立 12V DC-DC 稳压模块

参考图：`reference_drawings/mid360 DCDC.png`

| 参数 | 数值 | 来源 | 备注 |
|---|---:|---|---|
| 实物识别 | 黑色长方体外壳 | 用户纠正 | 不得与控制支路黑色 PCB DC-DC 混淆 |
| 外形尺寸 | 63 mm x 32 mm x 18 mm | 商家尺寸图 | 不含线缆伸出 |
| 安装孔距 | 56 mm | 商家尺寸图 | 单向孔距 |
| 安装孔孔径 | Φ4 mm | 商家尺寸图 | 两侧耳孔 |
| 线材长度 | 130 mm | 商家尺寸图 | 用于走线参考 |
| 是否第一层安装 | 待定 | 布局待确认 | 可根据空间和 Mid360 走线放第一层或第二层 |

---

## 7. 第二层开关相关输入

第二层开关不直接决定第一层底板外形，但会影响第一层走线、固定点和层间空间。

### 7.1 PWR-MOT-001 急停按钮

参考图：`reference_drawings/急停按钮.png`

| 参数 | 数值 | 来源 | 备注 |
|---|---:|---|---|
| 蘑菇头直径 | 40 mm | 商家尺寸图/BOM |  |
| 正面宽度 | 41.5 mm | 商家尺寸图 | 图中正视图标注 |
| 安装孔径 | 约 22.1 mm | 用户实测/补充 | 商家图未按实测精确，设计按实测值 |
| 触点模块尾部深度 | 46.5 mm | 商家尺寸图 | 第二层尾部和线束需避让 |
| 蘑菇头高度段 | 21.3 mm / 30.5 mm | 商家尺寸图 | 图中侧视标注 |
| 安装位置 | 第二层尾部一侧 | 用户决策 | 需保证易触达 |

### 7.2 PWR-003 主电源开关

参考图：`reference_drawings/电源开关旋钮.webp`

| 参数 | 数值 | 来源 | 备注 |
|---|---:|---|---|
| 旋钮宽度 | 35 mm | 商家尺寸图 | 图中标注 |
| 总高度 | 52 mm | 商家尺寸图 | 图中标注 |
| 面板下方深度 | 30 mm | 商家尺寸图 | 第二层尾部和线束需避让 |
| 安装直径 | 22 mm | 商家尺寸图 | 后续可按实物复核 |
| 接线螺杆直径 | 4 mm | 商家尺寸图 | 主电源线端子空间需避让 |
| 安装位置 | 第二层尾部另一侧 | 用户决策 | 与急停分置两侧 |

---

## 8. 轮胎窗口与底盘形状假设

| 参数 | 数值 | 来源 | 备注 |
|---|---:|---|---|
| 底板形状 | 非标准矩形，四轮位置做边缘缺口 | 用户决策 | 不是底板内部封闭窗口，而是从左右边缘向内切掉矩形缺口 |
| 选定电机支架姿态下缺口长度估计 | 约 65 mm | 用户补充 | v0.1 初值按 70 mm，后期根据实物尽量调小 |
| 另一种支架姿态下窗口长度估计 | 约 90 mm | 用户补充 | 当前不采用 |
| 缺口长度 | 70 mm | 用户确认/v0.1 草案 | 沿车体前后方向 |
| 缺口切入深度 | 40 mm | 用户确认/v0.1 草案 | 从左右底板边缘向内切入 |
| 缺口圆角 | R6 | v0.1 草案 | 避免尖角应力集中 |
| 轮胎内侧到支架电机安装面外侧距离 | 约 9.1 mm | 单侧轮系装配 v0.1 | 用于支架与缺口关系 |
| 轮胎内侧到第一排支架孔中心距离 | 约 19.2 mm | 单侧轮系装配 v0.1 | 正常伸出状态量测值，用于支架孔位侧向定位 |
| 轮胎内侧到第二排支架孔中心距离 | 约 43.5 mm | 单侧轮系装配 v0.1 | 用于支架孔位侧向定位，正式加工前仍需复核 |

---

## 9. 第一层硬件放置优先级

### 9.1 第一层优先放置

1. PWR-004 主电池托盘。
2. PWR-MOT-004 双路电机驱动板，数量 2。
3. WIRE-001 分路保险盒 / 负极汇流排。

### 9.2 可根据空间放第一层或第二层

1. CTRL-002 STM32 控制板。
2. COMP-001 Orin NX 独立 DC-DC 稳压电源模块。
3. CTRL-001 控制支路 DC-DC 电源模块。
4. SENS-009 Mid360 独立 12V DC-DC 稳压模块。

---

## 10. 待确认项

1. 第一层底板材料和最终板厚。
2. 轴距；轮距当前 v0.1 基线为 `175 mm`，仍需随实物装配复核。
3. 四个轮胎窗口的最终尺寸、圆角和位置。
4. 电机支架底部孔位相对底板窗口的精确位置。
5. 默认垫柱高度，当前仅建议 6 mm 起步。
6. 两块电驱板是否改为第二层底板下方安装，以及摆放方向和电机线出线方向。
7. 分路保险盒在第一层的具体位置，以及拆卸维护所需线束余量。
8. STM32、Orin NX DC-DC、控制支路 DC-DC、Mid360 DC-DC 是否进入第一层 v0.1 布局，或统一转入第二层布局验证。
9. 层间高度和第二层底板对保险盒、开关尾部、线束弯折空间的影响。
10. 板材重量估算与电机驱动能力校核。

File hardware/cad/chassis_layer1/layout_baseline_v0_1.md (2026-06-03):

# 第一层底板布局基准草案 v0.1

状态：草案，待人工确认和 CAD 草模验证。

本文基于 `design_inputs.md` 推导第一层底板 v0.1 的机械基准，包括底板外形、轮胎窗口、轴距、轮距和电机支架孔位策略。本文不替代 `design_inputs.md`，不表示 CAD 已完成。

---

## 1. 坐标约定

1. 底板平面使用右手坐标系。
2. `X` 轴为车体前后方向，正方向为车头。
3. `Y` 轴为车体左右方向，正方向为车体左侧。
4. 原点位于第一层底板几何中心。
5. 单位均为 mm。

---

## 2. 底板初始外形

| 参数 | 初值 | 说明 |
|---|---:|---|
| 底板长度 X | 270 | 用户试摆估算 |
| 底板宽度 Y | 208.4 | 左右轮系装配 v0.1 外包宽度 |
| 半长 | 135 | 用于窗口位置计算 |
| 半宽 | 104.2 | 用于窗口位置计算 |
| 板厚 | 3 | v0.1 建模初值，最终随材料和强度确认 |

### 2.1 板材重量粗估

按完整矩形 `270 x 208.4 mm`、四个轮胎边缘缺口 `70 x 40 mm` 估算，开缺口后净面积约：

```text
270 * 208.4 - 4 * 70 * 40 = 45068 mm^2 = 450.68 cm^2
```

若板厚取 3 mm，净体积约 `135.2 cm^3`。

| 材料 | 密度估算 | 开窗后板重估算 | 备注 |
|---|---:|---:|---|
| 亚克力 | 1.18 g/cm^3 | 约 160 g | 轻，但开缺口后抗冲击和裂纹需谨慎 |
| FR4/G10 玻纤板 | 1.8-1.9 g/cm^3 | 约 243-257 g | 刚度和绝缘性较好 |
| 碳纤板 | 1.5-1.7 g/cm^3 | 约 203-230 g | 轻且刚，但导电和加工粉尘需注意 |
| 铝板 | 2.70 g/cm^3 | 约 365 g | 刚度好，但需处理绝缘和边缘毛刺 |

v0.1 CAD 先按 `3 mm` 建模。材料最终选择留待电机负载、加工方式和成本一起判断。

---

### 2.2 下一轮长度候选

第一层底板装配验证快照显示，当前 `270 mm` 长度下，四轮边缘缺口到前后板边余量约为：

```text
135 - 90 - 70/2 = 10 mm
```

该余量对角部立柱、层间连接和亚克力板刚度偏紧。下一轮建议保持 `180 mm` 轴距不变，优先试算：

| 底板长度 | 半长 | 缺口到前/后板边余量 | 说明 |
|---|---:|---:|---|
| 290 | 145 | 20 | 下一轮优先验证，可显著改善前后窄边和立柱孔位余量 |
| 300 | 150 | 25 | 更宽裕备选，刚度和立柱布置更从容，但整车长度增加 |

---

## 3. 轮胎窗口初始方案

### 3.1 窗口尺寸

| 参数 | 初值 | 依据 |
|---|---:|---|
| 缺口长度 X | 70 | 用户估计当前支架姿态约 65 mm，v0.1 增加约 5 mm 余量，后续根据实物尽量调小 |
| 缺口切入深度 Y | 40 | 从左右底板边缘向内切入，用户确认 |
| 缺口圆角 | R6 | 避免尖角应力集中，便于加工 |

### 3.2 窗口中心位置

v0.1 采用边缘缺口，而不是底板内部封闭窗口。四个缺口从左右边缘向内切入：

| 缺口 | 中心 X | 边缘侧 | 说明 |
|---|---:|---:|---|
| 左前 | +90 | 左侧边缘 | 车头左侧 |
| 右前 | +90 | 右侧边缘 | 车头右侧 |
| 左后 | -90 | 左侧边缘 | 车尾左侧 |
| 右后 | -90 | 右侧边缘 | 车尾右侧 |

由此得到：

| 参数 | 初值 | 说明 |
|---|---:|---|
| 轴距 | 180 | 前后轮轴中心距 |
| 轮距 | 175 | 左右轮轴中心距；由左右轮系装配 v0.1 确认 |
| 缺口到前/后板边余量 | 10 | `135 - 90 - 70/2` |
| 缺口内侧边界 Y | +/-64.2 | 半宽 104.2，切入深度 40 |
| 轮轴中心 Y | +/-87.5 | 轮距 175 |
| 轮胎装配半宽 | 约 18.02 | 轮胎与联轴器装配总宽约 36.04 |
| 轮胎与联轴器装配内侧 Y | 约 +/-69.48 | 与缺口内侧边界约 5.28 mm 余量 |
| 轮胎本体内侧 Y | 约 +/-70.8 | 轮胎宽度 33.4 mm；与缺口内侧边界约 6.6 mm 余量 |
| 前后缺口内侧间距 | 110 | 中央硬件布置可用长度参考 |

该方案优点：

1. 缺口从边缘切入，避免封闭窗口占用过多底板面积。
2. 轮距和轴距都较紧凑，符合小车尺寸尽量小的目标。
3. 中央区域仍可放置电池托盘、电驱和保险盒。
4. 底板宽度与左右轮胎外包宽度基本对齐，符合“不超出轮胎外边”的 v0.1 目标。

该方案风险：

1. 缺口内侧到轮胎与联轴器装配内侧参考余量约 5.28 mm，仍需实物复核轮胎偏摆和联轴器偏心。
2. 轮距 175 mm 是否足够稳定，需要结合整车重心和上层 Mid360 高度复核。
3. 缺口长度 70 mm 依赖支架姿态判断，需实物装配后复核轮胎穿板范围。
4. 底板外边与轮胎外包基本齐平，后续若需要外壳、边缘保护或加工倒角，可能需要局部加宽或内收缺口形状。
5. 当前 `270 mm` 长度下前后窄边约 `10 mm`，不利于角部立柱和亚克力板抗晃，下一轮优先试 `290 mm`，`300 mm` 作为备选。

---

## 4. 电机支架安装孔策略

电机支架固定在第一层底板下方。v0.1 原则：

1. 支架底板安装孔完全落在第一层底板下方的实体区域内。
2. 支架底部孔位不跨越轮胎窗口。
3. 支架孔到窗口边缘保留足够材料，建议不小于 6-8 mm。
4. 支架孔到板边也建议不小于 6-8 mm。

### 4.1 已知支架参数

| 参数 | 数值 |
|---|---:|
| 支架底部外形 | 40 x 42.4 |
| 支架底部安装孔 | 4 x Φ4 |
| 支架底部孔距 | 30 x 23.4 |
| 轴心到底板安装面下表面距离 | 约 33.673 |
| 另一支架姿态轴心距安装面 | 约 19 |

### 4.2 当前几何假设

用户目标为：

1. 电机本体与地面保持更大距离；
2. 轮胎窗口约 65 mm，而不是约 90 mm；
3. 第一层底板面积尽量大。

因此 v0.1 草案按“轴心到底板安装面下表面距离约 33.673 mm”的支架姿态推导。该值来自单侧轮系装配 v0.1 量测结果，仍需通过实物支架、电机、轮胎和底板相对位置复核。

### 4.3 待实物确认的关键偏移

目前采用以下支架孔位关系作为 v0.1 初值：

```text
支架底部孔中心矩形在 X 方向与轮胎缺口中心对齐。
轮胎内侧到第一排支架孔中心距离约为 19.2 mm。
轮胎内侧到第二排支架孔中心距离约为 43.5 mm。
```

按 `轮距 175 mm`、`轮胎宽度 33.4 mm` 估算：

```text
轮胎本体内侧 Y = +/-70.8 mm
左侧第一排孔中心 Y ~= +51.6 mm
左侧第二排孔中心 Y ~= +27.3 mm
右侧第一排孔中心 Y ~= -51.6 mm
右侧第二排孔中心 Y ~= -27.3 mm
```

上述两排孔中心距离约为 24.3 mm，仍应视为装配量测近似值。v0.1 可用于草模，正式加工前应以实物孔位和支架 CAD 复核为准。

X 方向先假设支架孔中心矩形与缺口中心对齐：

```text
前轮支架孔 X = +90 +/- 15 mm
后轮支架孔 X = -90 +/- 15 mm
```

---

## 5. 第一层核心硬件布局原则

v0.1 先只放核心硬件占位：

1. 主电池托盘。
2. 两块双路电机驱动板。
3. 分路保险盒 / 负极汇流排。

可选硬件暂不强制放第一层：

1. STM32。
2. Orin NX DC-DC。
3. 控制支路 DC-DC。
4. Mid360 DC-DC。

建议布局优先级：

1. 主电池托盘尽量靠近底板中心，降低重心偏置。
2. 两块电驱靠近对应左右/前后电机线束，减少电机动力线长度。
3. 分路保险盒靠近电池输出和主开关走线路径，但保留拆卸空间。
4. 高电流线束尽量固定在板边或专门线束通道，不横跨轮胎窗口。

---

### 5.1 装配验证后的电驱位置问题

第一层底板装配验证快照显示，若两块电驱继续放在第一层底板上方，在当前底板尺寸下更容易被挤到最前端或最后端；理想的中部两侧位置空间不足。

下一轮候选方案：

1. 优先验证电驱安装在第二层底板下方，第二层布局入口见 `../chassis_layer2/`。
2. 保留第一层底板下方安装电驱作为备选，但需重点检查离地、轮胎、电机、线束、防护和维护。
3. 若电驱位置仍保持第一层上方，则需同步确认第二层能否容纳剩余硬件，并评估是否需要增加底板长度。

### 5.2 第二层联动验证

当前第一层空间基本刚好容纳主电池托盘、保险盒、电驱和下方电机模块。进入下一轮时，必须同步验证第二层是否可容纳：

1. STM32 控制板。
2. Orin NX 与安装板。
3. Orin NX 独立 DC-DC。
4. 控制支路 DC-DC。
5. Mid360 独立 DC-DC。
6. 急停按钮、主电源开关和线束弯折空间。

---

## 6. 下一步需要确认

1. 轮胎缺口初值 `70 x 40 R6` 是否在实物装配后仍满足避让。
2. 底板长度是否从 `270 mm` 增加到优先 `290 mm` 或备选 `300 mm`。
3. 轴距 `180 mm`、轮距 `175 mm` 是否作为 v0.1 初值继续推进。
4. 缺口内侧约 5.28 mm 装配参考余量是否足够。
5. 支架孔位草案是否与实物孔位一致。
6. 电驱是否改为第二层底板下方安装。
7. 第二层剩余硬件和线束路径是否可容纳。

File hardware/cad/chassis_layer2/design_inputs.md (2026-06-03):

# 第二层底板设计输入

状态：草案，待尺寸复核和 CAD 草模验证。

本文记录第二层底板布局验证所需的硬件、层间空间、安装关系和候选参数。本文不替代 BOM、采购清单、DEC、架构文档或实物验证记录。

---

## 1. 设计目标

1. 验证第二层能否容纳第一层未放下的计算、控制、电源转换和开关硬件。
2. 优先验证两块双路电机驱动板安装在第二层底板下方。
3. 为第一层释放中部两侧空间，避免电驱被挤到最前端或最后端。
4. 保持急停按钮和主电源开关位于第二层尾部两侧，确保易触达。
5. 验证层间空间、线束弯折、维护拆装和绝缘安全。

---

## 2. 与第一层联动的基准参数

| 参数 | 数值 / 候选 | 来源 | 备注 |
|---|---:|---|---|
| 第一层轮距 | 175 mm | 左右轮系装配 v0.1 | 当前验证基准 |
| 第一层轴距 | 180 mm | 第一层布局基准草案 | 当前验证基准 |
| 第一层宽度 | 208.4 mm | 左右轮系装配 v0.1 | 与轮胎外包宽度对齐 |
| 第一层长度当前值 | 270 mm | 第一层装配验证 v0.1 | 前后窄边约 `10 mm`，偏紧 |
| 第一层长度优先候选 | 290 mm | 第一层装配验证 v0.1 | 前后窄边约 `20 mm` |
| 第一层长度备选 | 300 mm | 第一层装配验证 v0.1 | 前后窄边约 `25 mm` |
| 第二层初始外形 | 待验证 | 设计草案 | 可先跟随第一层 `290 x 208.4 mm`，再按硬件和开关外形调整 |
| 层间高度 | 待验证 | 设计草案 | 需覆盖保险盒高度、下挂电驱、线束弯折和维护空间 |

---

## 3. 第二层优先验证硬件

| 硬件 | 数量 | 候选位置 | 关键尺寸 / 约束 |
|---|---:|---|---|
| 双路电机驱动板 | 2 | 第二层底板下方，中部两侧 | 单板约 `58 x 50 mm`，端子最高约 `11.6 mm`，垫柱后高度需另算 |
| STM32 控制板 | 1 | 第二层上方 | 板外形约 `43.40 x 66.93 mm`，需预留排针和线束空间 |
| Orin NX 与安装板 | 1 套 | 第二层上方 | 固定板尺寸待确认，需保证散热和维护 |
| Orin NX 独立 DC-DC | 1 | 第二层上方或边侧 | 接线端子后长度约 `71.3 mm`，高度约 `17 mm` 不含垫柱 |
| 控制支路 DC-DC | 1 | 第二层上方或边侧 | 约 `60 x 30 mm`，高度约 `14 mm` 不含垫柱 |
| Mid360 独立 DC-DC | 1 | 第二层上方或靠近 Mid360 走线侧 | 外形约 `63 x 32 x 18 mm` |
| 急停按钮 | 1 | 第二层尾部一侧 | 安装孔约 `22.1 mm`，触点模块尾部深度约 `46.5 mm` |
| 主电源开关 | 1 | 第二层尾部另一侧 | 安装直径约 `22 mm`，面板下方深度约 `30 mm` |

---

## 4. 待验证项

1. 第二层底板外形是否跟随第一层 `290 x 208.4 mm`，还是局部加宽 / 加长。
2. 两块电驱下挂后，端子、线束和垫柱是否与第一层电池、保险盒、线束或层间立柱干涉。
3. 第二层上方是否能容纳 STM32、Orin NX、各 DC-DC、急停和主电源开关。
4. 角部立柱是否能获得足够边距，建议孔到板边和缺口边不小于 `8-10 mm`。
5. 层间高度是否满足保险盒维护、电驱散热、电源线弯折和开关尾部空间。
6. 若采用亚克力板，前后窄边和角部立柱区域是否足够抗晃。

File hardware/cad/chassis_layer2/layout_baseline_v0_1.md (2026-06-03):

# 第二层底板布局基准草案 v0.1

状态：草案，待人工确认和 CAD 草模验证。

本文基于第一层底板装配验证结论和 `design_inputs.md` 推导第二层底板 v0.1 的布局验证基准。本文不表示 CAD 已完成，也不代表最终加工方案。

---

## 1. 坐标约定

1. 与第一层底板保持同一平面坐标约定。
2. `X` 轴为车体前后方向，正方向为车头。
3. `Y` 轴为车体左右方向，正方向为车体左侧。
4. 原点建议与第一层底板几何中心对齐。
5. 单位均为 mm。

---

## 2. 底板外形候选

第一层装配验证显示 `270 mm` 长度前后窄边约 `10 mm`，对角部立柱和板材刚度偏紧。下一轮验证建议：

| 参数 | 优先候选 | 备选 | 说明 |
|---|---:|---:|---|
| 第一层长度 | 290 | 300 | `290 mm` 可将前后窄边提升到约 `20 mm`；`300 mm` 提升到约 `25 mm` |
| 第二层长度 | 290 | 300 | 初步跟随第一层，后续按开关尾部和线束调整 |
| 第二层宽度 | 208.4 | 待验证 | 初步跟随第一层轮胎外包宽度，不排除局部加宽 |
| 板厚 | 3 | 待验证 | 暂按第一层草案一致 |

---

## 3. 电驱下挂候选

优先验证两块双路电机驱动板安装在第二层底板下方：

1. 目标是释放第一层中部两侧空间。
2. 电驱应尽量靠近对应电机线束路径，减少动力线绕行。
3. 端子方向应便于电机线、主电源线和控制线分开固定。
4. 下挂高度需按电驱端子最高约 `11.6 mm`、垫柱高度、线束弯折和绝缘间隙共同验证。
5. 电驱下方不得与第一层电池、保险盒、线束、立柱或维护空间发生干涉。

备选方案：

1. 电驱安装在第一层底板下方。
2. 电驱仍安装在第一层上方但增加底板长度。

备选方案均需额外检查离地、防护、维护和线束风险。

---

## 4. 第二层上方硬件布局原则

第二层上方优先承载：

1. STM32 控制板。
2. Orin NX 与安装板。
3. Orin NX 独立 DC-DC。
4. 控制支路 DC-DC。
5. Mid360 独立 DC-DC。
6. 急停按钮和主电源开关。

布局原则：

1. 急停按钮和主电源开关放在尾部两侧，保证易触达。
2. Orin NX 保持散热和维护优先，不被线束和开关尾部遮挡。
3. STM32 靠近控制线束汇入区域，避免编码器线和 PWM/方向线过度绕行。
4. DC-DC 模块靠近对应负载和供电路径，但应避免高电流线束横穿控制信号区。
5. 线束应预留固定点和弯折半径，避免仅靠硬件端子承受拉力。

---

## 5. 立柱与层间空间

下一轮验证应优先检查：

1. 四角立柱孔位是否能落在前后加长后的实体区域内。
2. 立柱孔到板边、缺口边和硬件安装孔的距离是否足够，建议不小于 `8-10 mm`。
3. 层间高度是否能覆盖保险盒高度、第二层下挂电驱、线束弯折和维护空间。
4. 如果第二层下挂电驱，电驱与第一层保险盒 / 电池托盘之间应保留装配和散热间隙。
5. 如果使用亚克力板，需特别关注前后窄边、缺口圆角附近和立柱区域的抗晃能力。

---

## 6. 下一步需要确认

1. 第一层 / 第二层长度优先采用 `290 mm` 还是 `300 mm`。
2. 第二层宽度是否保持 `208.4 mm`，或是否为了开关、线束、立柱局部加宽。
3. 两块电驱下挂位置和端子方向。
4. 第二层上方各硬件初始摆放位置。
5. 层间高度初值。
6. 立柱孔位和数量。

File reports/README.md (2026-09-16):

# Report Index

| 报告 | 日期 | 说明 |
| --- | --- | --- |
| [v1.1.2 H60-only 四轮架空与断链停车](h60_no_orin_w2_m3_v1_1_2.md) | 2026-09-16 | 四轮架空前进/后退/STOP、真实链路断开定性停车及限制；当前为发布候选 |
| [v1.1.1 四轮单轮运动表征](h60_four_wheel_characterization_v1_1_1.md) | 2026-09-08 | 四轮单轮方向、编码器符号、工程 CPR、停车证据和适用限制 |
| [H60 + MC520 重建基线](h60_mc520_rebuild_baseline_2026-08-16.md) | 2026-08-16 | 当前数字基线、矛盾清理、未关闭风险和证据边界 |
| [Orin NX C1902 40W 综合压力测试](orin_nx_c1902_40w_mixed_stress_test_2026-06-14.md) | 2026-06-14 | 上一阶段的计算平台压力测试；不等同于整车业务负载验收 |

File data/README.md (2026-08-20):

# 数据与证据索引

本目录收录适合 Git 管理、可复核的数据索引、校验值和小型样例。原始 rosbag、完整日志和大体量数据保存在外部数据归档中。

运行数据优先写入 Orin NX 内置 NVMe；停止录制并检查有效性后，再将筛选、裁剪或压缩的关键数据复制到归档介质。外置介质不进入实时控制链路，复制失败也不得改变 STOP/DISARM 或底盘控制语义。

每个公开数据条目至少记录：采集日期、硬件/固件/软件版本、测试条件、字段或话题说明、单位、校验值、脱敏处理和已知限制。尚未取得真实数据时保持空目录，不生成伪造样例。

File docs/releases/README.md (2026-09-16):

# Project0 发布说明

这里保存面向读者的版本说明。根目录 [`CHANGELOG.md`](../../CHANGELOG.md) 用于快速浏览版本；每个版本文件用于完整说明成果、验证、限制和使用提示。

## 已发布说明

| 版本 | 类型 | 说明 |
| --- | --- | --- |
| `v1.1.2` | 阶段性成果版本 | [H60-only 四轮架空与断链安全基线](v1.1.2.md) |

## 已发布版本

| 版本 | 类型 | 说明 |
| --- | --- | --- |
| `v1.1.1` | 阶段性成果版本 | [四轮单轮运动表征基线](v1.1.1.md) |
| `v1.1-dev.2` | 历史开发预发布 | [H0 基线与 H60 安全控制检查点](v1.1-dev.2.md) |
| `v1.1-dev.1` | 历史开发预发布 | [P2 H60 + MC520 重建公开基线](v1.1-dev.1.md) |

历史标签保持原样。`v1.1.1` 是 P2 的首个阶段性成果版本，`v1.1.2` 继续冻结受限 H60-only 成果；两者都不替代最终 `v1.1` 的阶段验收。

## 阅读说明

- “本次成果”只列可独立理解和复用的交付结果。
- “验证与证据”说明结论覆盖了什么。
- “已知限制”明确哪些能力仍不能由该版本推出。
- “使用或升级提示”给出读者复现或迁移时必须注意的事项。
- 开发流水和内部治理过程不进入公开发布说明。

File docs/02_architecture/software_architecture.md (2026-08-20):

# 1. 文档定位

> **当前实现覆盖（2026-08-20）**：ROS2 包职责与上层接口骨架继续有效，但底盘桥接目标已从旧 STM32 文本协议迁移为 H60 版本化协议和显式 ARM 会话。当前无独立急停/继电器或急停 GPIO。现有源码中的 `ESTOP`、软件急停字段和 `p0_safety_manager` 行为属于旧平台迁移骨架，不得解释为 H60 新车已实现能力，也不得直接用于运动；现行停止/失能语义应迁移为 STOP、DISARM、故障锁止和新会话 ARM。固件要求见 `../../firmware/h60_motion_control_firmware_requirements_v0_2.md`。

本文档属于项目0在 P1 阶段的系统架构设计输出物之一，放置在 docs/02_architecture/ 目录下，与 system_architecture.md、compute_comm_architecture.md、power_architecture.md、hardware_architecture.md 并列管理。

根据项目文件结构设计，software_architecture.md 是 P1 阶段正式架构文档之一，用于承接系统总架构中未展开的软件实现层内容，并为后续 interface_definition.md、docs/03_design/ 下的各模块设计文档、docs/04_deployment/ 下的部署运行文档提供上位软件骨架。

本文档的目标不是直接替代源代码目录说明、接口字段定义表或 launch 具体实现，而是为迭代一单车系统提供可运行、可联调、可验收的软件基线，以支撑 P2–P6 的底盘控制、传感器接入、定位建图、导航避障、语义导航、任务调度与集成验收。

----------------------------------------

# 2. 阶段归属与依赖关系

项目0总体流程采用 P0-P10 分阶段推进方式，其中 P1 的本质是“功能落地、技术选型与工程准备”，P2 才进入“底盘与基础运动成立”，P3 进入“感知与定位建图成立”，P4 进入“导航与避障成立”，P5 进入“语义导航与任务调度成立”，P6 进入“系统集成与迭代一验收”。

因此，软件架构文档属于 P1 的正式输出，直接服务于以下后续阶段：

* P2：建立底盘桥接软件骨架、底盘控制链路、启动与调试脚本基础、基础自检与状态观测能力；
* P3：建立 Mid360 / D435 接入链路、建图链路、定位链路、地图管理链路与数据记录基础；
* P4：建立导航避障链路、安全保障链路与模式切换链路；
* P5：建立语义导航、任务调度与语义位置查询链路；
* P6：完成系统管理、运行准入、状态聚合、记录复盘与迭代一验收支撑。
本文档的直接前置依赖包括：

* 项目定义输入，用于锁定项目整体定位、约束、迭代边界与成果目标；
* system_architecture.md，用于提供“执行层—感知层—空间认知层—行动规划层—任务决策层”的五层主链路骨架，以及“安全保障链路—系统管理链路—数据记录与复盘链路”的三条辅助链路骨架；
* compute_comm_architecture.md，用于提供 Orin NX 作为主计算与 ROS2 主承载平台、STM32 作为底层执行控制平台的计算与通信边界；

本文档的直接后继文档包括：
* interface_definition.md：承接本文档中的架构级接口关系，进一步落实为话题、服务、动作名称与字段定义；
* docs/03_design/ 下各模块详细设计文档：承接本文档中的软件包职责边界，展开到节点、参数、状态机与实现逻辑；
* docs/04_deployment/ 下部署运行文档：承接本文档中的 workspace 结构、模式启动方式与运行依赖；
* docs/06_testing/ 下测试文档：承接本文档中的最小闭环、状态观测与验收相关支撑点。

----------------------------------------

# 3. 软件架构设计目标

结合项目0的系统定位、客观约束、主观需求、迭代路线与整体成果要求，项目0软件架构在 P1 阶段应同时满足以下目标：

## 3.1 支撑迭代一最小闭环成立

软件架构必须优先服务于迭代一平台主干能力成立，而不是追求一开始就做成高复杂度、多分支、研究型重架构。

因此，软件架构首先要保证以下闭环可逐步成立：

* 底盘控制与状态回传闭环；
* 传感器接入与建图闭环；
* 地图加载、定位与导航闭环；
* 语义目标解析与任务执行闭环；
* 安全监测、系统管理、数据记录三条辅助闭环。

## 3.2 与总架构保持一致而不重复定义总架构

本文档不是对 system_architecture.md 的重新定义，而是在既有总架构骨架上的软件层展开。

因此，本文档必须严格承接总架构中的：

* 五层主链路骨架；
* 三条辅助链路骨架；
* 真实走廊场景、真机闭环验收、安全底线优先、平台属性优先的总原则。

## 3.3 与计算与通信架构保持一致

软件架构必须服从 compute_comm_architecture.md 中已经确定的计算与执行边界：Orin NX 负责主计算、ROS2 主业务与系统协调，STM32 负责底层电机执行、底层状态采集与硬实时相关控制，不运行 ROS2 主业务。

因此，软件架构必须体现以下原则：

* ROS2 主业务统一承载于 Orin NX；
* STM32 通过底盘桥接包接入 ROS2 世界；
* 软件分层不能让底盘固件越级理解导航、任务和语义；
* 软件接口组织应服务于串口 / USB / 以太网等既定通信通道，而不重新发明跨层职责。

## 3.4 满足单人可实施、可维护、可扩展

项目0由单人推进，软件架构必须避免多工作区、多主控、多套不稳定软件栈并行演进造成的复杂度失控。

因此，软件架构必须做到：

* 结构清晰；
* 职责边界稳定；
* 最小闭环可独立验证；
* 问题可定位、数据可记录、状态可复盘；
* 迭代二应以已验收软件基线为起点，并为受控研究增强预留空间。

----------------------------------------

# 4. 架构边界声明

## 4.1 本文档明确纳入的内容

本文档明确纳入以下内容：

* ROS2 软件总体承载方式；
* 软件主工作区组织原则；
* 主要软件包划分；
* 各软件包的一句话职责边界；
* 主链路与辅助链路的软件映射关系；
* 架构级数据流、控制流、状态流；
* 架构级话题 / 服务 / 动作接口关系；
* 模式化启动的软件组织原则；
* 迭代一到迭代二的软件演进边界。

## 4.2 本文档明确不纳入的内容

本文档明确不纳入以下内容：

* 具体节点名、回调逻辑与类设计；
* 具体接口字段定义与消息文件最终格式；
* 具体算法流程细节与参数取值；
* Nav2、SLAM、驱动等第三方组件的参数调优细节；
* 串口协议字段级设计；
* 具体部署命令、编译命令与环境安装步骤；
* 具体测试用例、指标与实验流程；
* STM32 固件内部任务划分细节。

## 4.3 后续应由其他文档承接的内容

以下内容应由后续文档承接：

* interface_definition.md：承接具体消息、服务、动作定义与跨包接口表；
* docs/03_design/：承接底盘控制、感知、SLAM、导航、语义导航、任务调度、运行约束、系统管理等模块的详细设计；
* docs/04_deployment/：承接 ROS2 workspace 搭建、Orin NX 环境部署、运行说明与远程开发方案；
* docs/06_testing/：承接测试计划、验收标准、测试场景与测试记录；

----------------------------------------

# 5. 软件总体承载方式

项目0采用以 Orin NX 为主计算平台、以单一主 ROS2 workspace 为软件主承载结构的软件架构。

这里的“单一主 ROS2 workspace”含义是：项目0在 Orin NX 上以一套统一的 ROS2 工程空间承载迭代一的主业务软件包、自定义接口包、启动组织、配置文件与运行脚本，以降低单人开发过程中的依赖分裂、构建分裂与版本分裂风险。

STM32 不运行 ROS2 主业务，不参与主工作区中的 ROS2 包组织；STM32 作为底层执行控制平台，以独立固件工程形式存在，并通过 p0_base_bridge 与 ROS2 世界交互。

该承载方式同时符合以下约束与要求：

* 工程优先于花哨功能；
* 真机主线、仿真辅助；
* 安全底线优先；
* 固定场景单车闭环优先于高复杂度功能；
* 后续需保留研究增强空间。

----------------------------------------

# 6. 软件主工作区与仓库组织关系

公开仓库采用 project0/ 作为统一根目录，其中 docs/、firmware/、src/、config/、scripts/、data/、experiments/、simulation/、reports/、presentation/ 等目录共同构成公开工程与成果资料。

在软件架构层，建议将项目总仓库根目录同时作为 ROS2 主工作区根目录使用，避免额外再套一层独立 workspace 目录，从而降低单人维护复杂度，并保持与文件结构设计方案一致。

推荐目录关系如下：

```text
project0/
├── docs/
├── firmware/
├── src/
├── config/
├── scripts/
├── data/
├── experiments/
├── simulation/
├── reports/
├── presentation/
├── README.md
├── CHANGELOG.md
└── .gitignore
```

其中与软件架构直接相关的核心目录含义为：

* src/：ROS2 所有功能包，按职责拆包；
* config/：全局参数 YAML / Lua，与 launch 配合；
* scripts/：环境初始化、启动、关闭、自检、数据录制与分析脚本；
* data/：rosbag、地图文件、日志、标定数据等运行数据的索引与管理入口；大文件不入 Git，介质分层与保留规则见 `data/README.md`；
* docs/：架构、设计、部署、标定、测试等非代码文档；

----------------------------------------

# 7. 软件包划分总览

项目0软件架构采用“统一接口包 + 启动组织包 + 主链路功能包 + 辅助链路功能包 + 第三方依赖”的结构。

建议的核心软件包如下：

* p0_interfaces：统一定义项目内部自定义消息、服务、动作接口；
* p0_bringup：统一组织模式化启动，不承载业务逻辑；
* p0_sensor_drivers：统一承接 Mid360、D435 等传感器接入；
* p0_manual_control：将经复验的手柄输入转换为带死人开关语义的手动底盘意图；
* p0_base_bridge：统一承接 ROS2 与 STM32 底盘控制板之间的桥接；
* p0_mapping：承接建图能力；
* p0_localization：承接定位能力；
* p0_map_manager：承接地图加载、保存、语义位置表管理与空间语义查询；
* p0_navigation：承接目标导航、路径执行与导航状态反馈；
* p0_semantic_nav：承接语义目标解析与导航目标生成；
* p0_task_manager：承接任务生命周期管理与多步骤任务组织；
* p0_safety_manager：承接安全监测、异常处置仲裁与安全状态输出；
* p0_system_manager：承接模式管理、状态聚合、运行准入与系统级协调；
* p0_data_tools：承接记录、打点、回放辅助与实验支撑；
----------------------------------------

# 8. 总架构到软件包的映射关系

本文档不是对系统总架构的重新定义，而是将总架构骨架落实为软件包组织。

显式映射关系如下：

| 总架构层 / 链路 | 对应软件包 |
| --- | --- |
| 执行层 | p0_base_bridge |
| 感知层 | p0_sensor_drivers |
| 空间认知层 | p0_localization、p0_mapping、p0_map_manager |
| 行动规划层 | p0_navigation |
| 任务决策层 | p0_semantic_nav、p0_task_manager |
| 安全保障链路 | p0_safety_manager |
| 系统管理链路 | p0_system_manager、p0_bringup |
| 数据记录与复盘链路 | p0_data_tools |
| 统一接口支撑 | p0_interfaces |

该映射关系体现了以下原则：

* 软件层必须忠实承接五层主链路与三条辅助链路；
* 安全、系统管理、数据记录是长期并存的支撑骨架，不是后期补丁；
* 执行层在软件上并不直接承载为 STM32 ROS2 节点，而是通过 p0_base_bridge 完成跨层桥接；
* 统一接口必须独立成包，以避免跨包重复定义和接口失控。

----------------------------------------

# 9. 各软件包职责边界

## 9.1 p0_interfaces

作用：统一定义项目0内部跨包通用的自定义 msg / srv / action，避免各包私自定义重复数据结构。

边界：本包只负责接口定义，不承载业务逻辑，不承载状态机，不承载具体处理算法。

## 9.2 p0_bringup

作用：统一组织系统启动入口、运行模式入口与组合启动方式，不承载业务逻辑。

边界：本包只负责启动编排，不负责导航算法、安全判断、任务决策与数据处理。

## 9.3 p0_sensor_drivers

作用：统一承接激光雷达、深度相机等传感器接入，并向上提供标准化感知数据流。

边界：本包负责“接入与转发”，不承担地图管理、导航决策与任务理解。

## 9.4 p0_base_bridge

作用：统一承接 ROS2 世界与 STM32 固件世界之间的控制指令下发、状态回传、通信状态监测与桥接转换；旧平台实现将通信新鲜度门限参数化，并对 STM32 四路有符号 16-bit 瞬时计数独立解绕，再进行方向归一化和每轮 counts/rev 换算。

边界：本包只处理“底盘控制与反馈桥接”，不应越级承担任务、语义与导航理解逻辑。轮径 / 轮距未标定前，不由累计轮转数生成轮速、odom、TF 或位姿积分。

## 9.4A p0_manual_control

作用：将手柄 `Joy` 输入转换为带死人开关、失效超时和明确来源的手动底盘指令。

边界：本包不直接发布最终底盘指令，只向 `p0_safety_manager` 提供手动意图；设备映射未确认、死人开关释放、`Joy` 超时或 Flydigi USB 心跳无进度超过 `0.30s` 时必须输出非活动零指令。

## 9.5 p0_mapping

作用：承接建图模式下的地图生成与相关状态输出。

边界：本包只负责建图，不承担语义位置解释、任务管理与系统模式仲裁。

## 9.6 p0_localization

作用：承接加载既有地图后的定位能力输出，为导航提供当前位置与定位质量信息。

边界：本包负责“我在哪”，不负责“我要去哪”与“任务是否结束”。

## 9.7 p0_map_manager

作用：承接地图文件的加载、保存、切换、元数据管理，以及语义位置表与语义空间映射数据的统一管理。

边界：本包负责“地图与语义空间数据的管理”，不直接承担语义输入解析与任务决策。

## 9.8 p0_navigation

作用：承接导航目标执行、路径跟踪、局部避障与导航状态反馈。

边界：本包负责“如何走到目标点”，不负责“目标是否成立”与“任务是否结束”。

## 9.9 p0_semantic_nav

作用：承接语义输入解析，并将语义目标转换为可执行的导航目标。

边界：本包负责“理解语义并转目标”，不负责底层路径执行，不负责维护整条任务生命周期。

## 9.10 p0_task_manager

作用：承接任务生命周期管理、多步骤任务组织、任务状态维护与与导航执行结果的衔接。

边界：本包负责“任务是否成立、任务是否结束、是否进入下一步”，不负责底层导航算法实现。

## 9.11 p0_safety_manager

作用：集中承担安全监测、异常事件聚合、安全判断与安全处置仲裁。

边界：局部包可以输出自身状态，但停止、失能、人工/自动控制权与恢复条件应由一个运行仲裁点集中处理，避免多个包同时发布相互冲突的运动命令。现有包名 `p0_safety_manager` 是旧迁移标识，不代表产品安全能力。

## 9.12 p0_system_manager

作用：集中承担系统模式管理、运行准入、模块状态聚合、故障等级汇总与系统级协调。

边界：本包负责“系统是否允许进入某种模式、当前系统整体状态如何”，不替代任务管理与安全管理的专属职责。

## 9.13 p0_data_tools

作用：承接 rosbag 录制、日志组织、关键状态打点、数据导出与回放辅助支撑。

边界：记录链路应是伴随式支撑，不能侵入主业务决策，也不能把业务决策建立在记录链路之上，否则后期调试和发布版本会高度耦合。

----------------------------------------

# 10. 主链路的软件组织

项目0软件主链路按“感知输入 → 空间认知 → 行动规划 → 任务决策 → 底盘控制”组织。
在软件包层面，可表达为：

```text
p0_sensor_drivers
        ↓
p0_mapping / p0_localization / p0_map_manager
        ↓
p0_navigation
        ↓
p0_semantic_nav / p0_task_manager
        ↓
p0_safety_manager ← p0_manual_control
        ↓
p0_base_bridge
        ↓
STM32 firmware
```

但从职责顺序上更准确的理解应为：

```text
感知输入
→ 空间认知成立（建图 / 定位 / 地图管理）
→ 任务决策给出导航目标
→ 行动规划执行导航
→ 底盘控制执行运动
```

原因在于：任务决策层逻辑上位于行动规划层之上，语义导航和任务管理负责产生或组织目标，导航负责执行该目标，底盘桥接负责把执行结果落到 STM32 与底盘执行世界。

因此，项目0软件主链路在职责视角下应表述为：

```text
p0_sensor_drivers
→ p0_mapping / p0_localization / p0_map_manager
→ p0_semantic_nav / p0_task_manager
→ p0_navigation
→ p0_safety_manager（导航 / 手动意图仲裁）
→ p0_base_bridge
→ STM32
```

该主链路支撑的不是抽象演示，而是面向真实走廊场景的真机闭环平台能力。

----------------------------------------

# 11. 辅助链路的软件组织

项目0软件辅助链路按“安全、管理、记录”三条长期并存的骨架组织。

## 11.1 安全保障链路

安全保障链路的核心软件包是 p0_safety_manager。

它持续接收来自感知、底盘、定位、导航、系统等环节的状态或事件输入，进行统一安全判断与安全处置仲裁，并在必要时要求系统减速、停车、保持或进入安全模式。

该链路之所以必须独立，是因为项目0明确面向包含楼梯口、天井边缘、电梯口等高风险环境区域的真实场景，安全底线能力不能作为可选附加项存在。

## 11.2 系统管理链路

系统管理链路的核心软件包是 p0_system_manager 与 p0_bringup。

其中：

* p0_bringup 负责把系统以某种模式组织起来；
* p0_system_manager 负责模式切换、状态聚合、运行准入与系统级协调。

该链路的意义在于，项目0迭代一不仅要“能跑”，还要形成一个可解释、可管理、可复盘的项目系统。

## 11.3 数据记录与复盘链路

数据记录链路的核心软件包是 p0_data_tools。

它不直接决定主业务动作，但持续为以下事项提供支撑：

* rosbag 记录；
* 结构化日志留痕；
* 关键状态打点；
* 回放辅助；
* 对比实验支撑。

该链路之所以必须长期保留，是因为项目0整体成果中明确要求实验日志、问题日志、测试记录、版本快照、复盘记录与可解释过程沉淀，而不是只形成一个“碰巧能跑”的系统。

`p0_data_tools` 负责录制、打点、导出、回放辅助和数据索引，不负责把外置介质直接耦合进主业务逻辑。运行时数据先写入 Orin NX 内置 NVMe；停止录制并检查有效性后，再将筛选、裁剪或压缩的关键数据复制到外置机械硬盘。U 盘只承担换机和日常周转，不作为 Project0 原始 rosbag 长期仓库。

存储介质失效、未挂载或复制失败不得改变底盘控制、运行仲裁和 STOP/DISARM 语义。外置机械硬盘只在小车停止后的维护阶段连接，不作为运动中实时录制介质。

----------------------------------------

# 12. 架构级接口组织原则

软件架构文档需要定义“接口如何组织”，但不需要在本阶段把字段级定义全部写死。

因此，本文档只定义接口组织原则与架构级接口关系，具体字段与名称由 interface_definition.md 承接。

## 12.1 接口分层原则

项目0内部接口分为三类：

* 数据型接口：主要由 topic 承担，用于持续传输传感器数据、底盘状态、定位结果、导航状态、系统状态等；
* 请求响应型接口：主要由 service 承担，用于模式切换、地图保存加载、语义位置查询、STOP/DISARM 等；
* 长时任务型接口：主要由 action 承担，用于导航执行、语义导航任务等存在过程反馈与结果返回的任务。

## 12.2 接口统一归口原则

凡是跨包通用、且标准消息无法直接表达的结构，统一收口到 p0_interfaces 中定义。

典型结构包括：

* 底盘控制与状态结构；
* 系统状态结构；
* 安全事件结构；
* 定位质量结构；
* 语义目标结构；
* 任务状态结构。
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

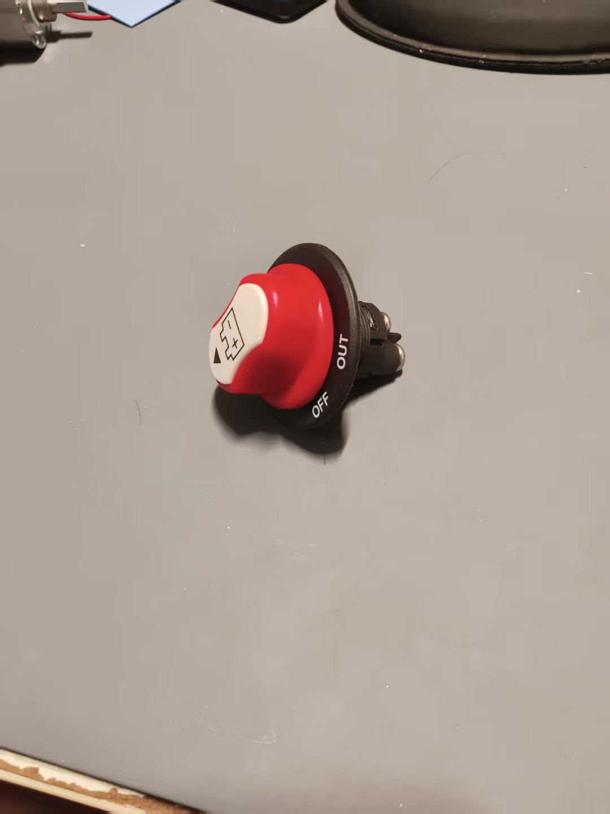
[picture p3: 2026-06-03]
hardware/reference_images/power/PWR-003_main_power_switch_red_knob_top.jpg

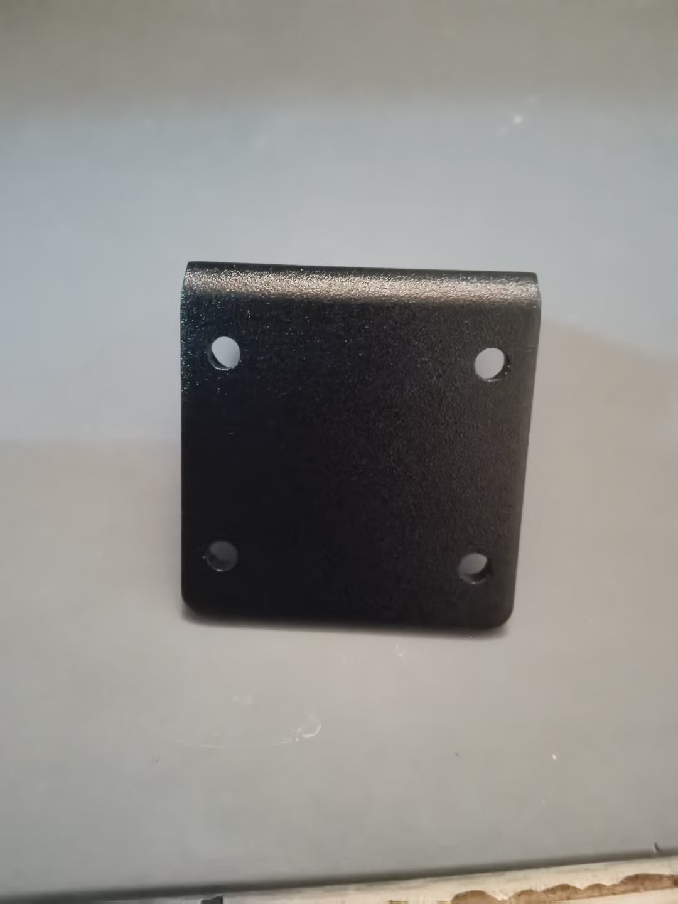
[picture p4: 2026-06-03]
hardware/reference_images/drive/PWR-MOT-008_motor_mount_plate_top.jpg

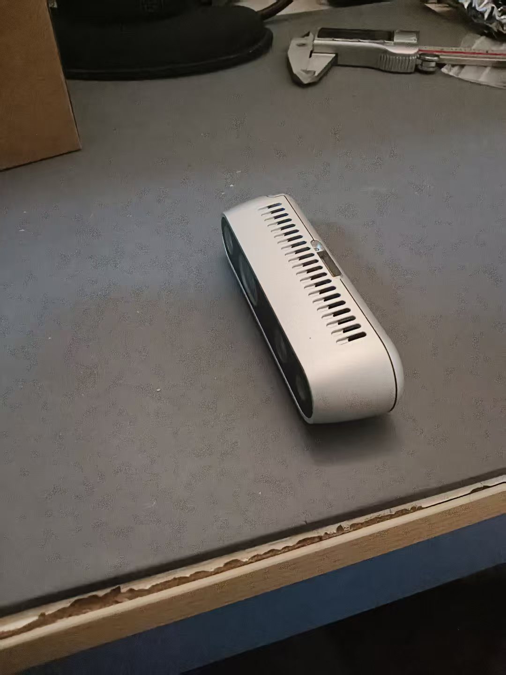
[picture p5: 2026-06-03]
hardware/reference_images/sensing/EXIST-004_realsense_d435_top.jpg

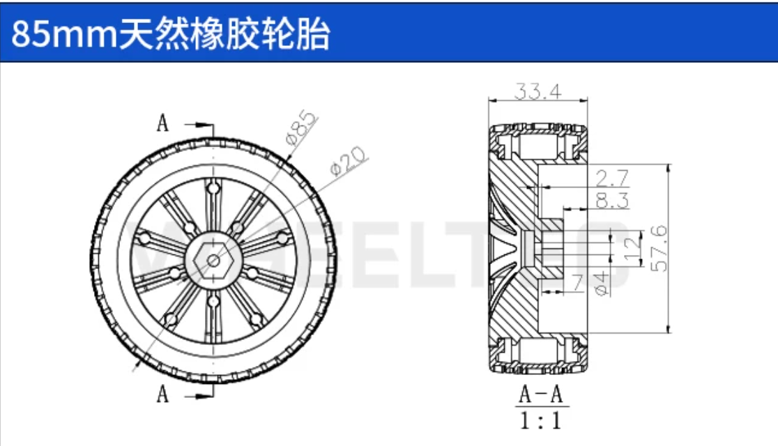
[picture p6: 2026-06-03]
hardware/cad/chassis_layer1/reference_drawings/轮胎.png

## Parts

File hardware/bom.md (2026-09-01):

# Project0 当前整车 BOM

> 文档状态：正式 / P2 重建主件台账
> 适用阶段：P2 及后续迭代一维护
> 最近收敛：2026-08-20（当前 H60 硬件边界统一）
> 文件定位：记录当前整车采用的主要硬件、关键规格、装车状态和验证入口。

> **当前状态覆盖**：2026-08-16 的现场反馈是整车已经拆散并处于零件状态，但当前公开快照没有重新确认新件已下单、到货或安装。下文旧“已装车”只代表拆散前最后一次验证快照，不能推断当前仍安装、仍接线或可上电。

## 1. 维护边界

本 BOM 只记录会影响以下事项的硬件：

1. 系统功能和软件配置；
2. 电源、停车和运动约束；
3. 接口、接线和通信；
4. 结构安装和传感器位姿；
5. 故障定位、维修和替换。

以下内容不逐件纳入 BOM：

1. 通用螺丝、螺母、垫片、铜柱、尼龙柱；
2. 扎带、扎带座、线夹、标签和普通热缩管；
3. 杜邦端子、管型端子等通用耗材；
4. 电烙铁、万用表、示波器、热风枪和压线钳等工具。

上述小件按实际装车需要配置。影响供电、运动风险和复现的线径、保险规格、关键连接器和信号线仍在本 BOM 或 `hardware/wiring/` 中记录。

## 2. 状态口径

| 当前主表状态 | 含义 |
| --- | --- |
| 已批准待采购/确认 | 方案已选定，但本轮未核实采购、到货或实物型号 |
| 旧件待现场盘点 | 上一辆小车曾使用，目前存在性、完好性和复用状态未确认 |
| 设计已批准/器件待冻结 | 拓扑已确定，具体保护器件和额定值待实物与负载证据 |

到货、采购、供应商、价格和内部采购过程不由公开 BOM 维护。

## 3. 当前重建主件总表

| item_id | 主件 | 型号 / 关键规格 | 数量 | 当前状态 | 说明 |
| --- | --- | --- | ---: | --- | --- |
| CTRL-006 | 一体化底层控制板 | XTARK OpenCTR H60 V3.7 | 1 | 已批准待采购/确认 | 四路 AT8236、四路编码器、PC0 VIN ADC；实物版本和运动控制固件待验 |
| PWR-MOT-009 | 编码器减速电机 | MC520P56_12V 升级带壳，1:56，13线霍尔 AB | 4 | 已批准待采购 | 标称额定0.3A、堵转3A、额定150rpm；商品参数待台架复核 |
| PWR-MOT-010/011/012 | 配套支架/联轴器/轮 | 37支架、6mm铜联轴器、65mm橡胶轮 | 4套 | 已批准随套件采购 | 用户新 CAD 承接安装和包络 |
| WIRE-005 | 电机六芯线 | XH2.54 6Pin 配套线 | 4套 | 已批准随套件采购 | 到货后逐芯通断与针序复核 |
| EXIST-001 / COMP-004 | 主计算 | Orin NX 16GB / C1902 V1.1 | 1 | 电气异常后送专业维修 / 停用 | 损坏位置、根因与核心模组状态未确认；维修结论和重新验收前不回装、不上电 |
| EXIST-002 | 主激光雷达 | Livox Mid360 | 1 | 旧件待现场盘点 | 独立 SENS-009 12V 支路，历史功能记录不等于当前完好 |
| EXIST-004 | 深度相机 | Intel RealSense D435 | 1 | 旧件待现场盘点 | Orin USB 供电/数据 |
| PWR-001/PWR-006/PWR-003 | 主电源入口 | 3S电池、25A主保险、外置主开关 | 1套 | 旧件待现场盘点 | 保留主保险；电池/BMS/开关状态待复核 |
| COMP-001 | Orin DC-DC | 9-36V输入、12V输出 | 1 | 输出异常 / 停用待更换 | 旧件不得重试或用3S电池旁路；替换件仍须空载和带载验收 |
| SENS-009 | Mid360 DC-DC | 10-36V输入、12V 3A输出 | 1 | 旧件待现场盘点 | Mid360 独立支路；低电量和14W峰值待验 |
| PWR-DIST-002 | 带保护分配节点 | 主汇流 + H60/Orin/Mid360 三路支路保护 | 1套 | 设计已批准/器件待冻结 | 保险额定按线径、端子和实测负载冻结 |

## 4. 上一实车主件快照（历史）

以下表格保留 STM32/JGB/WSDC/三层平台拆散前的最后验证状态。它不再是当前采购、CAD、接线或验收依据。

### 4.1 计算与人工接管

| item_id | 主件 | 型号 / 关键规格 | 数量 | 历史快照状态 | 说明 |
| --- | --- | --- | ---: | --- | --- |
| EXIST-001 | Jetson Orin NX 核心模组 | Orin NX 16GB，512GB SSD | 1 | 已装车 / 基础功能复验通过 | Reference BSP、冷启动、网络、ROS2 与外设基础功能通过；最终固定和整车负载待验 |
| COMP-004 | Orin NX 载板 | C1902 V1.1 | 1 | 已装车 / 基础功能复验通过 | JetPack 6.2.1 rev. 1 / L4T R36.4.4 与 UARTA 回环通过；固定、防松和整车负载待验 |
| COMP-001 | Orin NX DC-DC | IIO-PW936 1-4，9-36V 输入，12V 输出 | 1 | 已装车 / 待复验 | 计算支路独立供电；DC5525 中心正 |
| MAN-001 | 人工接管手柄 | 飞智黑武士2 | 1 | USB / Linux 输入复验通过 | 当前采用 Flydigi Android 模式；ROS2 teleop 和整车控制未完成；本条仅为旧平台快照 |
| MAN-002 | 手柄 USB 接收器 | 飞智黑武士2专属 2.4G 接收器 | 1 | USB / HID / 重启复验通过 | `04b4:2411`，由 `usbhid` / `hid-generic` 驱动；人工接管输入不替代硬件急停 |

### 4.2 感知

| item_id | 主件 | 型号 / 关键规格 | 数量 | 历史快照状态 | 说明 |
| --- | --- | --- | ---: | --- | --- |
| EXIST-002 | 主激光雷达 | Livox Mid360 | 1 | 已装车 / 基础功能复验通过 | 100BASE-TX、点云 / IMU 和 120 秒稳定性通过；最终固定、长期温升和 ROS2 驱动待验 |
| EXIST-003 | Mid360 一分三线 | M12 接口，电源 / 以太网 / 功能线 | 1 | 已装车 / 待复验 | 实际线序和接线以原始线缆标识及接线记录为准 |
| SENS-009 | Mid360 DC-DC | UENPO S3，10-36V 输入，12V 3A / 36W 输出 | 1 | 已装车 / 待复验 | Mid360 独立供电支路 |
| SENS-001/002 | Mid360 安装组件 | 顶部平台与增高支撑组件 | 1 套 | 已装车 / 待复验 | 视场、紧固和跌落后结构状态待复验 |
| EXIST-004 | 深度相机 | Intel RealSense D435 | 1 | 已装车 / 基础功能复验通过 | USB3、RGB / 深度各 30 帧通过；最终固定、长期稳定性和 ROS2 驱动待验 |
| SENS-007 | D435 数据线 | USB 3.0 Type-C | 1 | 已装车 / 待复验 | 连接可靠性和防拉扯状态按 P2 清单复查 |
| SENS-003 | D435 前向支架 | 固定 5 度支架 | 1 | 已装车 / 待复验 | 视场、固定和后续标定状态单独记录 |
| SENS-004/005/006 | 补光组件 | 灯体、控制器和支架 | 1 套 | 暂不采用 | 当前批次暂缓，不属于当前硬件缺口 |

### 4.3 底层控制与状态采集

| item_id | 主件 | 型号 / 关键规格 | 数量 | 历史快照状态 | 说明 |
| --- | --- | --- | ---: | --- | --- |
| CTRL-002 | STM32 控制板 | STM32F407VET6 核心板 / 开发板 V5.5 | 1 替换件 + 1 故障件 | 替换件供电 / SWD / UART / 三路编码器验收通过；原板故障隔离 | 替换板当前运行新映射 UART / 编码器低功率验收固件并保持电机安全输出；正式控制协议和 `LF` 替换后四路复验待完成 |
| CTRL-001 | 控制支路 DC-DC | 7-38V 输入，5V 固定输出，长期不超过 5A | 1 | 已装车 / 待复验 | 为 STM32、编码器和采样模块供电 |
| CTRL-004 | 电池电压采样模块 | Keyes 0-25V，5 倍分压模拟输出 | 1 | 已装车 / 待功能验收 | ADC 读取和阈值逻辑尚需验证 |
| CTRL-005 | 动力电流采样模块 | ACS712-30A，5V，约 66mV/A | 1 | 已装车 / 待功能验收 | 零点、比例和 ADC 采样尚需标定 |
| WIRE-004 | Orin-STM32 UART 线束 | 24AWG 三芯屏蔽线，GND / TX / RX | 1 | 已装车 / 双向与重启复验通过 | TX/RX 交叉，不传输 5V；正式控制协议尚未完成 |
| SWD-001 | STM32 外置 SWD 维护线 | GND / SWDIO / SWCLK，RST 按调试器能力接入 | 1 | 已装车 / 待复验 | 5VO 默认不接，避免反供电 |

### 4.4 动力与轮系

| item_id | 主件 | 型号 / 关键规格 | 数量 | 历史快照状态 | 说明 |
| --- | --- | --- | ---: | --- | --- |
| PWR-MOT-004 | 双路电机驱动板 | WAYNESTARK WSDC2412D-V3.0 | 2 | 已装车 / 已完成基础动力验证 | 控制逻辑和安全边界见数据手册、接线及固件记录 |
| PWR-MOT-005 | 带编码器减速电机 | JGB37-520-12100，12V，约 110RPM 额定转速 | 4 已装车 + 1 替换件待到货 | `LR / RF / RR` 编码器通过；`LF` 故障待替换 | `LF` 经交叉测试定位为电机内置编码器 / 内部连接器 / 原厂尾线侧故障；用户已购买替换电机，型号与线序待到货复核；阶段 D 未开放 |
| PWR-MOT-006 | 轮胎 | 约 83-85mm 实心轮胎 | 4 | 已装车 / 待复验 | 跌落后检查轮胎、紧固和转动状态 |
| PWR-MOT-007 | 轮毂联轴器 | 抱紧式六角联轴器 | 4 | 已装车 / 待复验 | 跌落后检查松动、偏摆和轴连接 |
| PWR-MOT-008 | 电机安装支架 | JGB-520 配套固定支架 | 4 | 已装车 / 待复验 | 跌落后检查支架和紧固 |

### 4.5 主电源、分配与急停

| item_id | 主件 | 型号 / 关键规格 | 数量 | 历史快照状态 | 说明 |
| --- | --- | --- | ---: | --- | --- |
| PWR-001 | 主电池 | 定制 3S，11.1V 标称，12.6V 满电，21Ah，带 BMS | 1 | 已装车 / 待复验 | 当前电池状态和负载表现以 P2 测试为准 |
| PWR-002 | 主电池入口连接器 | XT60，主干使用 12AWG | 1 套 | 已装车 / 待复验 | 主输入极性、绝缘和防拉扯需持续检查 |
| PWR-006 | 主输入保险 | ATO / ATC 25A，保险座主线 12AWG | 1 在用 + 备件 | 已装车 / 待复验 | 位于电池正极后、主开关前；不得短接或擅自增大规格 |
| PWR-003 | 主电源总开关 | 旋钮式电瓶断电开关 | 1 | 已装车 / 待复验 | 串联在主输入正极路径 |
| WIRE-001 | 分路保险盒 / 负极汇流排 | 6 路 ATO / ATC，M6 主端子 | 1 | 已装车 / 待复验 | 支路分配和保险配置以接线记录为准 |
| PWR-MOT-001 | 硬件急停按钮 | 40mm 蘑菇头，1NO + 1NC，自锁复位 | 1 | 已装车 / 待跌落后复验 | NC 控制继电器切断动力；NO 状态反馈仍需确认 |
| PWR-MOT-003 | 急停继电器 | JD2912 12V 40A 四脚继电器 | 1 | 已装车 / 待跌落后复验 | 只切断动力支路，不切断计算、控制和感知支路 |

### 4.6 机械结构

| item_id | 主件 | 型号 / 关键规格 | 数量 | 历史快照状态 | 说明 |
| --- | --- | --- | ---: | --- | --- |
| MECH-001/002/003 | 三层底板 | 三层铝合金底盘冻结结构 | 1 套 | 已装车 / 待跌落后复验 | 上一平台冻结 CAD 与装配历史；不作为新车加工基线 |
| PWR-004 | 主电池托盘 | 定制 / 3D 打印托盘 | 1 新件 + 1 破损件 | 新件已打印 / 待装车验收 | 原托盘在 2026-06-18 跌落后一侧破损；新托盘已重新打印，仍需尺寸、外观、承载、固定和装车复验 |
| PWR-005 | 主电池固定绑带 | 配套绑带 | 2 | 已具备 / 待复验 | 与托盘共同承担电池限位 |

## 5. 当前关键线材与连接边界

当前接线事实源是 `hardware/wiring/h60_power_wiring_v0_2.md`。下表是待 H2/H3 根据实物冻结的设计边界；不继承旧 STM32、旧电驱或旧轮系的线径、端子、线色和支路保险值。

| 用途 | 当前口径 |
| --- | --- |
| 主电池入口与高电流主干 | 实物线径、端子、长度、环境和 25A 主保险协调后冻结 |
| H60 / Orin / Mid360 三条支路 | 按各自实测峰值电流、启动冲击、线径与端子能力独立冻结 |
| 电机、编码器与 H60 低压信号 | 以 MC520/H60 实物针序与配套线复核结果为准 |
| Orin-H60 UART | 三芯信号线 + 掉电不反灌缓冲/隔离；线径与端子待实物冻结 |
| 主输入保险 | 25A ATO / ATC |
| 主电池连接器 | XT60 |
| Orin NX 电源连接器 | DC5525，中心正；上电前再测极性 |

精确线色、端子、实际偏差、屏蔽层接地和现场接线结果以 `hardware/wiring/` 为事实源。

## 6. 当前验证入口

1. 当前重建与运动准入：`docs/06_testing/p2_h60_mc520_rebuild_acceptance_plan_2026-08-16.md`
2. 当前电源、运动约束与采样边界：`docs/02_architecture/h60_power_motion_sampling_boundary.md`
3. 当前电源与接线：`hardware/wiring/h60_power_wiring_v0_2.md`
4. H60 运动控制固件要求与旧 STM32 历史：`firmware/`
5. Orin NX 和 H60 部署：`docs/04_deployment/`
6. 本表按器件、数量、工程状态和验收依据维护。

## 7. 后续维护规则

1. 新增主件、替换型号或移除当前采用件时更新本 BOM。
2. 普通耗材补货不更新本 BOM。
3. 测试是否通过不在 BOM 中展开，只更新状态摘要并链接原始记录。
4. 采购价格和链接不回填到 BOM。
5. 不以“硬件齐备”替代装车、通电、通信、传感器或运动验收。

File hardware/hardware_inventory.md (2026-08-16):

# 已有硬件清单

> **历史盘点**：本文形成于上一平台阶段，内容可能反映当时持有或装车状态，不代表 H60 重建时的实时库存。当前目标配置见 [bom.md](bom.md)，实物仍需 H0 重新盘点。

## 状态
- 草案

## 1. 计算平台

### 1.1 Seeed Studio Jetson Orin NX 16GB 官方套件
- 核心模组：Jetson Orin NX 16GB
- 载板：J401
- 散热：套件自带散热风扇
- 存储：512GB SSD
- 备注：
  - 固态硬盘已加装散热片
  - RTC 已安装纽扣电池
  - 已确认购买 C1902 V1.1 载板作为后续替换候选；到货和装配验证前，本条仍记录当前已有 J401 套件事实。
- 主要参数：
  - 算力：100 TOPS
  - 以太网口：1 × RJ45
  - 网卡接口：1 × M.2 E-Key
  - USB：4 × USB 3.2（10Gbps）
  - Type-C：1 × USB 2.0
  - CSI：2 ×（双通道 15pin）
  - HDMI：1 × HDMI 2.1
  - 风扇接口：1 × 4pin（5V PWM）
  - CAN：1
  - RTC：1 × 2pin
  - UART：1 × 12pin
  - 供电电压：9–19V
  - 尺寸：130mm × 120mm × 58.5mm
  - 重量：180g

## 2. 传感器

### 2.1 Livox Mid360 激光雷达
- 型号：Mid360
- 当前用途：主激光雷达
- 详细参数：另见《Livox Mid-360 用户手册》
- 备注：与项目命名基线一致，统一记为 Mid360。

### 2.2 Livox Mid360 一分三线
- 接口形式：
  - 一端：12 芯 M12 航空插头母头
  - 另一端：电源线、以太网线、功能线
- 线序摘要：
  - 电源正：红、棕
  - 电源负：黑、蓝、白
  - 以太网：绿、粉、黄、黑
  - 功能线：灰（秒脉冲）、紫（GPS 输入）、灰粉（预留输出 IO）、红蓝（预留输出 IO）
- 备注：
  - 实际接线前应以 M12 管脚定义再次核对。

### 2.3 Intel RealSense D435 深度相机
- 型号：D435
- 角色：前向辅助深度/视觉传感器
- 主要参数：
  - 深度范围：约 0.3m–3m
  - 深度分辨率：1280 × 720
  - 视野：85.2° × 58°
  - RGB：有
  - 跟踪模块：无
  - 接口：USB 3.0 Type-C
  - 尺寸：90mm × 25mm × 25mm
  - 重量：72g

### 2.4 Intel RealSense D435 USB 3.0 Type-C 数据线
- 型号：Intel RealSense D435 USB 3.0 Type-C 数据线
- 当前用途：连接 D435 与 Orin NX
- 状态：已确认存在
- 备注：原包装线缆可直接用于当前链路。

## 3. 运动部件

### 3.1 轮胎 × 2
- 数量：2
- 单个重量：0.116kg
- 单个负载能力：50kg
- 胎皮宽度：33.4mm
- 轮胎直径：83mm
- 轮毂材质：塑料
- 胎皮材质：橡胶
- 连接方式：联轴器连接电机输出轴

## 4. 线材与辅料

### 4.1 耐高温硅胶线
- 数量：5 卷，共 100 米
- 规格：22AWG
- 颜色：白、棕、灰、紫、橙
- 导体材质：无氧镀锡铜丝
- 绝缘材质：硅橡胶
- 额定电压：300V
- 额定温度：-60℃ ~ 200℃

### 4.2 电子线
- 规格：1007 / 22AWG
- 颜色：橙、白、紫、灰、棕
- 导体材质：镀锡铜芯
- 额定电压：300V
- 绝缘材质：环保原料
- 额定耐温：80℃

### 4.3 热缩管
- 状态：已列入现有物料
- 规格：待补充

## 5. 工具与调试设备

### 5.1 安立信 T12 电烙铁

### 5.2 正点原子 DS100 手持数字示波器

### 5.3 德力西万用表

## 6. 人工接管输入设备

### 6.1 飞智黑武士2手柄
- 型号：飞智黑武士2手柄
- 当前用途：人工接管输入设备
- 状态：已确认存在
- 备注：与 2.4G USB 接收器配套使用。

### 6.2 2.4G USB 接收器
- 型号：飞智黑武士2专属 2.4G USB 接收器
- 当前用途：接收手柄输入并接入 Orin NX
- 状态：已确认存在
- 备注：作为 Orin NX USB 外设使用。

## 7. 清单备注
- 本清单仅整理已知现有硬件，不包含缺失件、采购件或未来新增件。
- 当前硬件命名基线应统一为：Mid360、D435、Jetson Orin NX 16GB。
- Mid360 详细规格以用户手册为准。
- 计算平台载板替换计划以 `hardware/bom.md` 的 COMP-004 和公开采购状态为准；C1902 V1.1 已购买待到货，散热能力、外接 RTC 电池、40W / MAXN SUPER 稳定性和装车适配尚未验证。

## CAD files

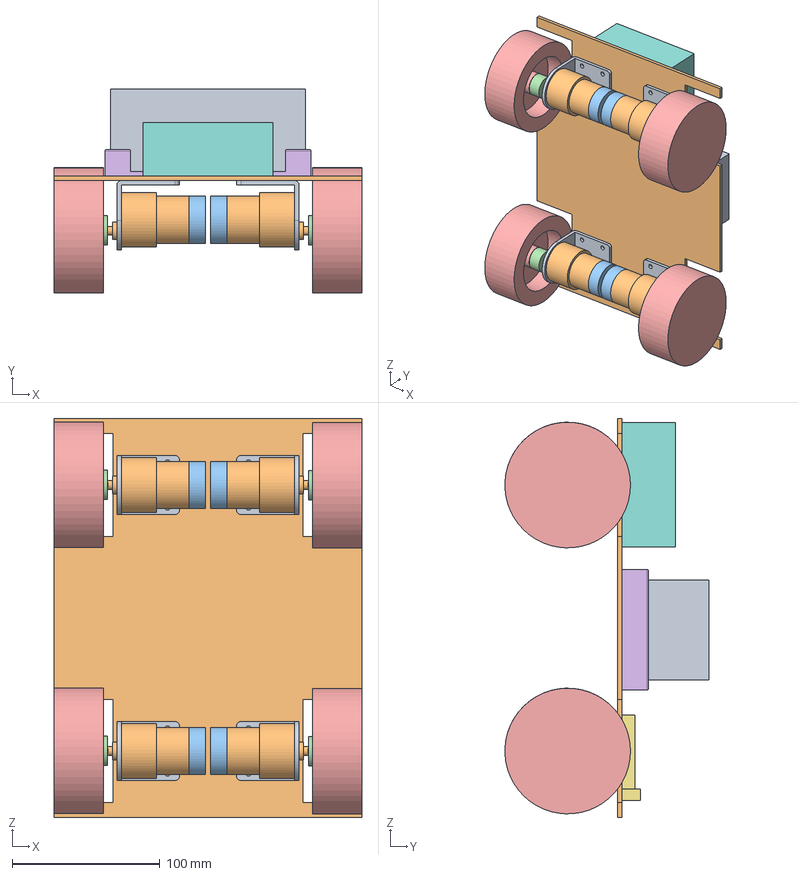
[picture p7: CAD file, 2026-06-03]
hardware/cad/chassis_layer1/verification/chassis_layer1_assembly_check_v0_1/final/chassis_layer1_assembly_check_v0_1.step
208.4 x 138.1 x 270.0 mm

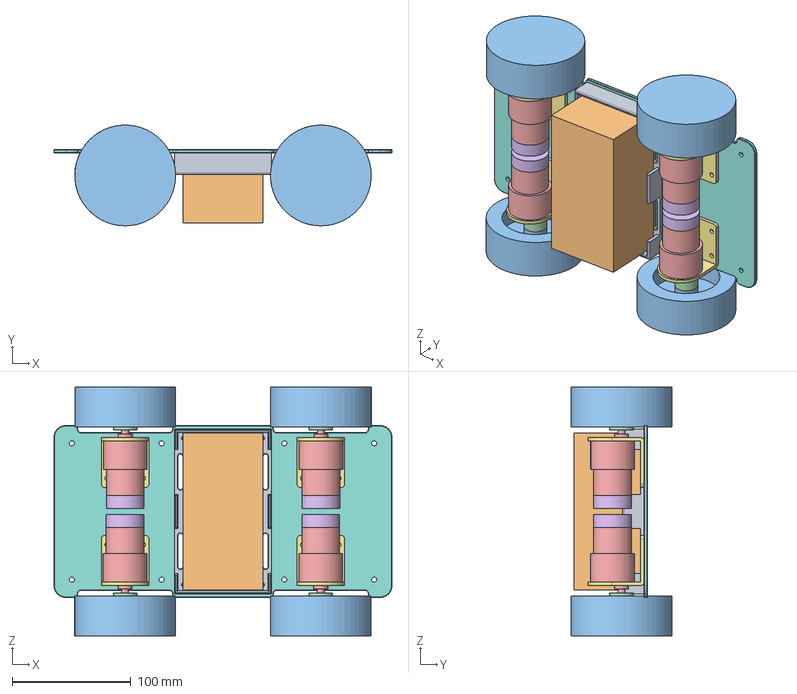
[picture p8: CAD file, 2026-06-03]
hardware/cad/chassis_three_layer_freeze_v0_1/assemblies/layer1_assembly_v0_1/final/layer1_assembly_v0_1.step
285.0 x 84.9 x 209.6 mm

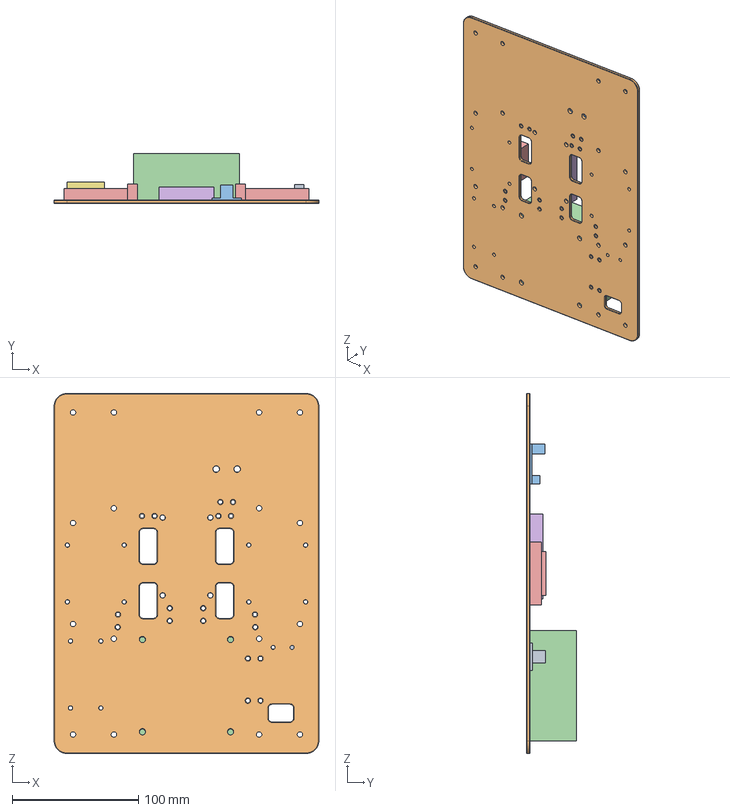
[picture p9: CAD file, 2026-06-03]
hardware/cad/chassis_three_layer_freeze_v0_1/assemblies/layer2_assembly_v0_1/final/layer2_assembly_v0_1.step
209.6 x 39.7 x 285.0 mm

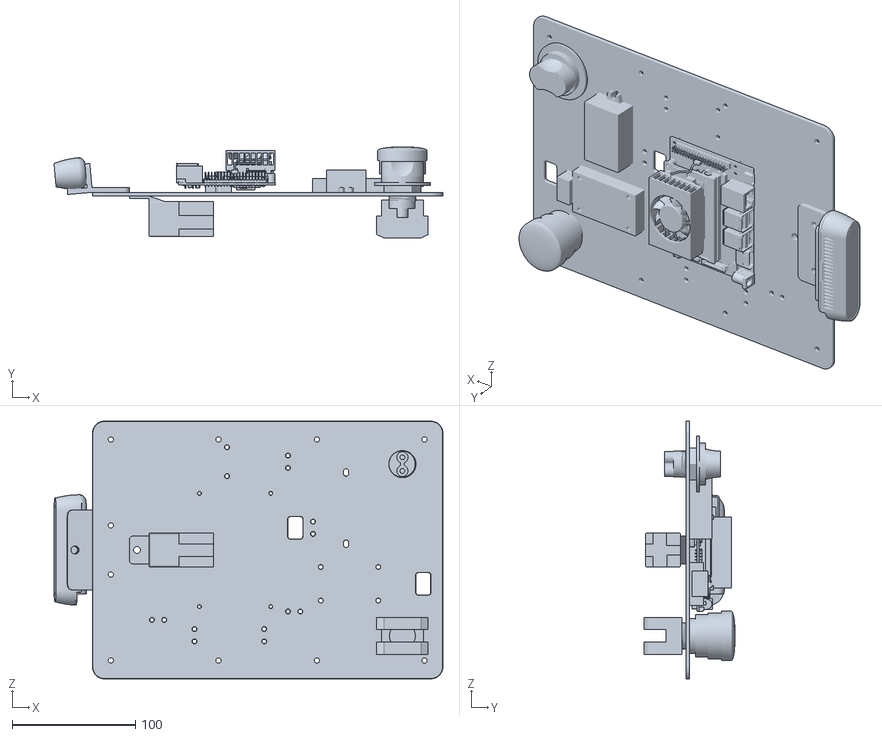
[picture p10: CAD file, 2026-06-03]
hardware/cad/chassis_three_layer_freeze_v0_1/assemblies/layer3_assembly_v0_1/preview/layer3_assembly_v0_1.stl
316.2 x 73.9 x 209.6

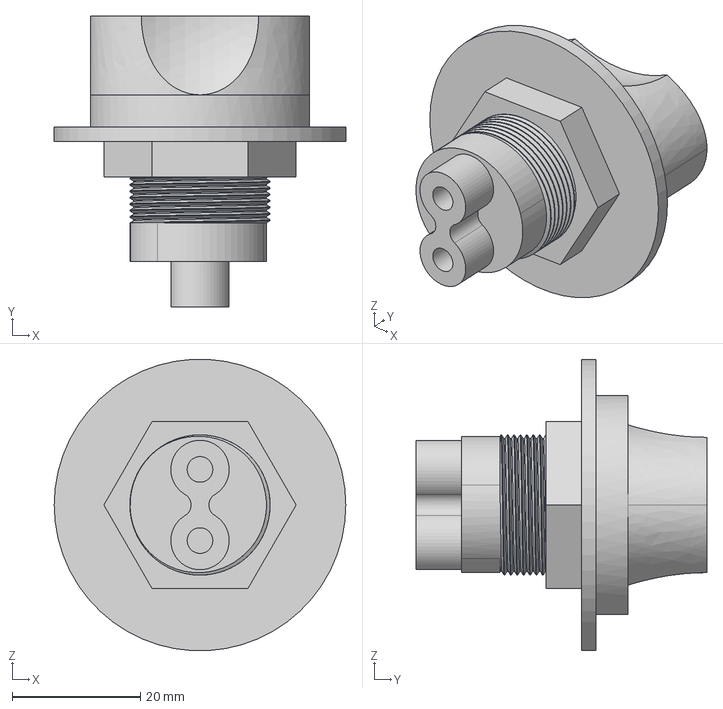
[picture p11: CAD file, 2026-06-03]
hardware/cad/hardware_assets_v0_1/main_power_switch_v0_1/final/main_power_switch_v0_1.step
45.5 x 45.4 x 45.4 mm

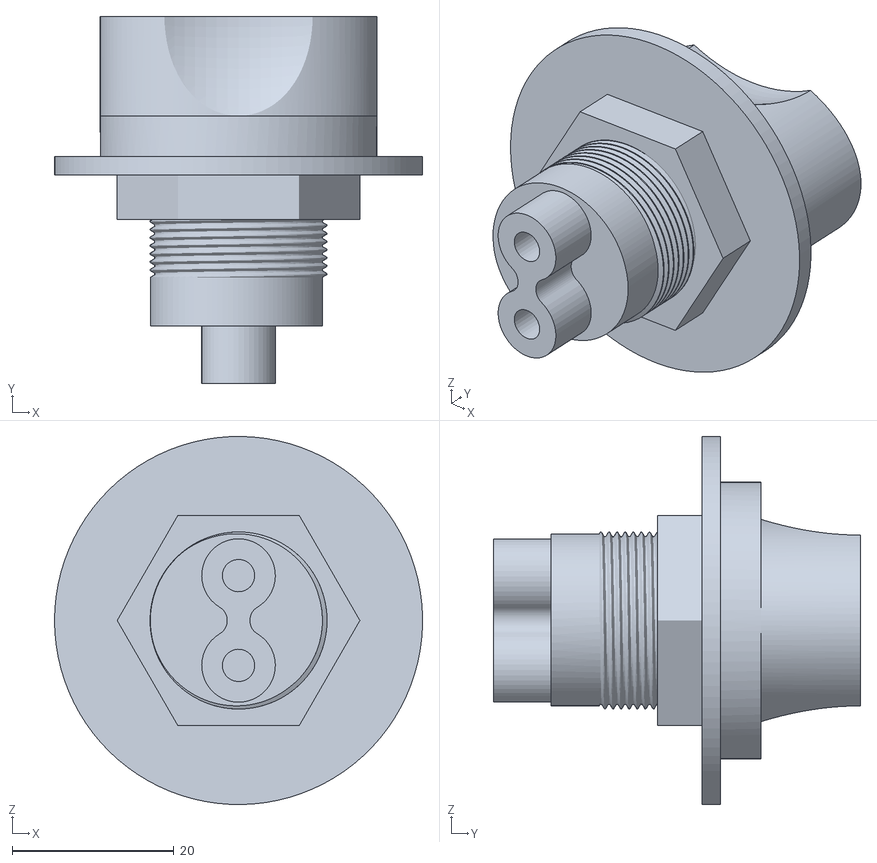
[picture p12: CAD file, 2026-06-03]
hardware/cad/hardware_assets_v0_1/main_power_switch_v0_1/preview/main_power_switch_v0_1.stl
45.5 x 45.4 x 45.5

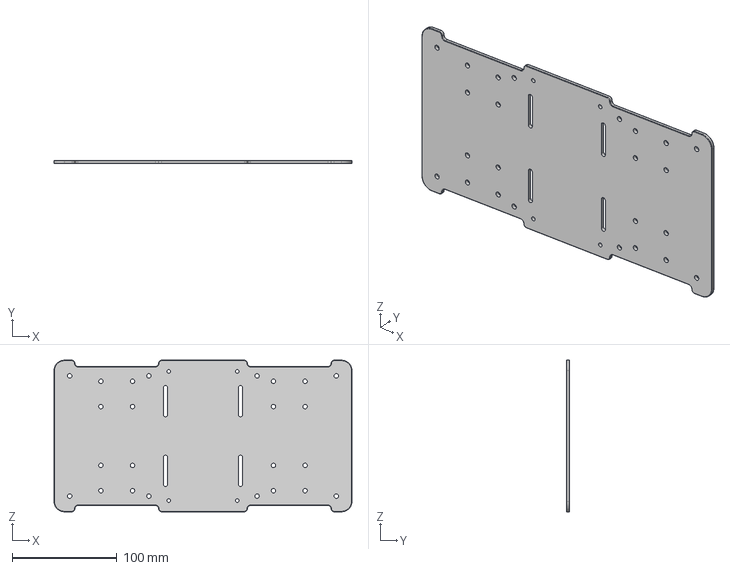
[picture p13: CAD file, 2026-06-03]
hardware/cad/chassis_three_layer_freeze_v0_1/plates/layer1_plate_v0_1/final/layer1_plate_v0_1.step
285.0 x 3.00 x 145.0 mm

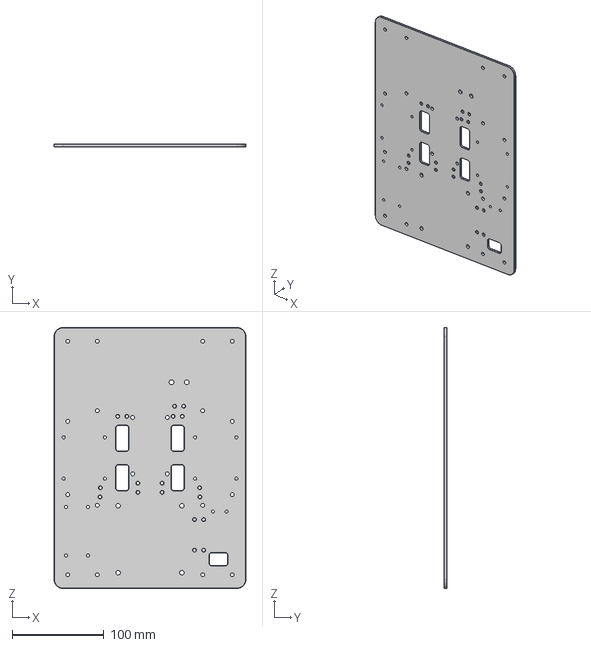
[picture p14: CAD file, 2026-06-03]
hardware/cad/chassis_three_layer_freeze_v0_1/plates/layer2_plate_v0_1/final/layer2_plate_v0_1.step
209.6 x 3.00 x 285.0 mm

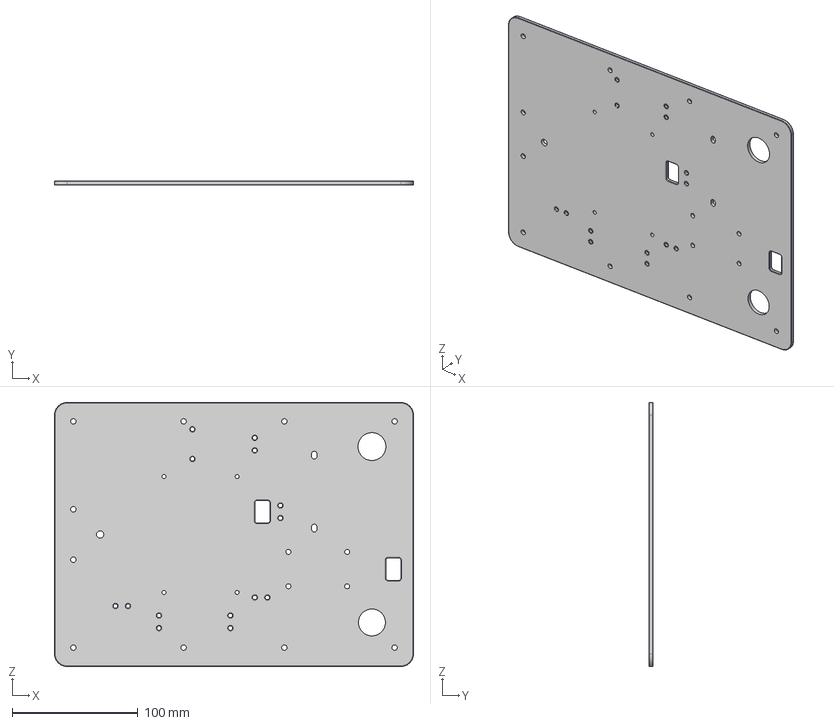
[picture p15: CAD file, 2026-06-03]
hardware/cad/chassis_three_layer_freeze_v0_1/plates/layer3_plate_v0_1/final/layer3_plate_v0_1.step
285.0 x 3.00 x 209.6 mm

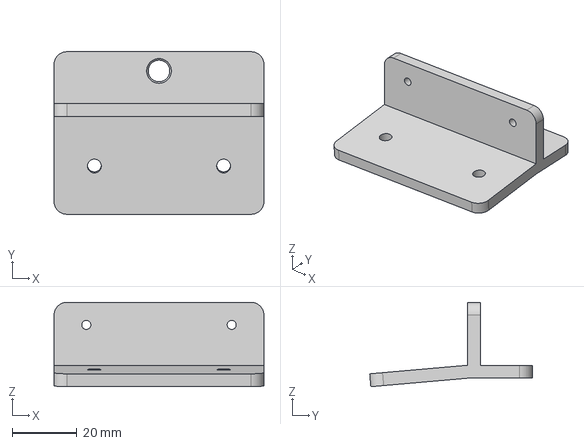
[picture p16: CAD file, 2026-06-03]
hardware/cad/chassis_three_layer_freeze_v0_1/supports/d435_fixed_5deg_mount_v0_1/final/d435_fixed_5deg_mount_v0_1.step
65.0 x 50.3 x 26.1 mm

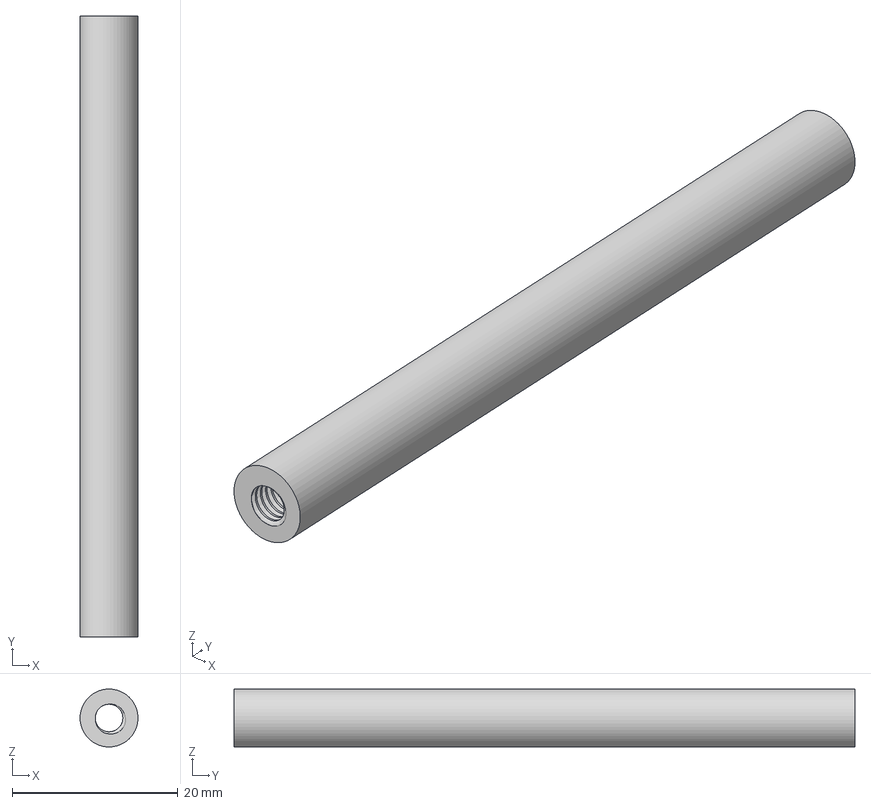
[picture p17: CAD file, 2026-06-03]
hardware/cad/chassis_three_layer_freeze_v0_1/supports/layer1_standoff_v0_1/final/layer1_standoff_v0_1.step
6.99 x 75.0 x 7.00 mm

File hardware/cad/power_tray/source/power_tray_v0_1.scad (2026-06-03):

// Project0 power battery tray, design draft v0.1
// Units: millimeters.
// This source is intended for review and parametric editing.

$fn = 64;

battery_length = 132.0;
battery_width = 67.7;
battery_height = 56.0;

inner_length = 133.5;
inner_width = 75.7;
wall_thickness = 3.0;
base_thickness = 3.0;
wall_height = 15.0;

outer_length = inner_length + wall_thickness * 2;
outer_width = inner_width + wall_thickness * 2;
total_height = base_thickness + wall_height;

strap_width = 26.0;
strap_thickness = 1.3;
strap_slot_length = 30.0;
strap_slot_width = 4.0;
strap_slot_radius = 2.0;
strap_slot_outer_margin = 3.0;
strap_slot_break_extra = 8.0;

mount_hole_diameter = 3.2;
mount_hole_center_offset = 8.0;

eva_length = 133.0;
eva_width = 75.0;
eva_thickness = 2.0;

module rounded_cube(size, r) {
    hull() {
        for (x = [-size[0] / 2 + r, size[0] / 2 - r])
            for (y = [-size[1] / 2 + r, size[1] / 2 - r])
                translate([x, y, 0])
                    cylinder(h = size[2], r = r);
    }
}

module rounded_slot_2d(length, width, radius) {
    hull() {
        translate([-length / 2 + radius, 0, 0])
            circle(r = radius);
        translate([length / 2 - radius, 0, 0])
            circle(r = radius);
    }
}

module strap_slot_cut(x, y) {
    translate([x, y, -0.1])
        linear_extrude(height = base_thickness + 0.2)
            rounded_slot_2d(strap_slot_length, strap_slot_width, strap_slot_radius);
}

module mount_hole_cut(x, y) {
    translate([x, y, -0.1])
        cylinder(h = base_thickness + 0.2, d = mount_hole_diameter);
}

module base_plate() {
    difference() {
        translate([0, 0, base_thickness / 2])
            cube([outer_length, outer_width, base_thickness], center = true);

        for (x = [-outer_length / 2 + mount_hole_center_offset,
                  outer_length / 2 - mount_hole_center_offset])
            for (y = [-outer_width / 2 + mount_hole_center_offset,
                      outer_width / 2 - mount_hole_center_offset])
                mount_hole_cut(x, y);

        for (x = [-inner_length / 4, inner_length / 4])
            for (y = [-outer_width / 2 + strap_slot_outer_margin + strap_slot_width / 2,
                      outer_width / 2 - strap_slot_outer_margin - strap_slot_width / 2])
                strap_slot_cut(x, y);
    }
}

module walls() {
    z = base_thickness + wall_height / 2;

    // Short end walls.
    translate([-inner_length / 2 - wall_thickness / 2, 0, z])
        cube([wall_thickness, outer_width, wall_height], center = true);
    translate([inner_length / 2 + wall_thickness / 2, 0, z])
        cube([wall_thickness, outer_width, wall_height], center = true);

    // Long side walls, split at the two strap positions.
    break_len = strap_slot_length + strap_slot_break_extra;
    side_y = inner_width / 2 + wall_thickness / 2;

    for (side = [-1, 1]) {
        for (seg = [
            [-outer_length / 2, -inner_length / 4 - break_len / 2],
            [-inner_length / 4 + break_len / 2, inner_length / 4 - break_len / 2],
            [inner_length / 4 + break_len / 2, outer_length / 2]
        ]) {
            translate([(seg[0] + seg[1]) / 2, side * side_y, z])
                cube([seg[1] - seg[0], wall_thickness, wall_height], center = true);
        }
    }
}

module power_tray() {
    union() {
        base_plate();
        walls();
    }
}

power_tray();

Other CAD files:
hardware/cad/chassis_layer1/verification/chassis_layer1_assembly_check_v0_1/preview/chassis_layer1_assembly_check_v0_1.stl
hardware/cad/chassis_three_layer_freeze_v0_1/assemblies/layer1_assembly_v0_1/preview/layer1_assembly_v0_1.stl
hardware/cad/chassis_three_layer_freeze_v0_1/assemblies/layer2_assembly_v0_1/preview/layer2_assembly_v0_1.stl
hardware/cad/chassis_three_layer_freeze_v0_1/plates/layer1_plate_v0_1/preview/layer1_plate_v0_1.stl
hardware/cad/chassis_three_layer_freeze_v0_1/plates/layer2_plate_v0_1/preview/layer2_plate_v0_1.stl
hardware/cad/chassis_three_layer_freeze_v0_1/plates/layer3_plate_v0_1/preview/layer3_plate_v0_1.stl
hardware/cad/chassis_three_layer_freeze_v0_1/supports/d435_fixed_5deg_mount_v0_1/preview/d435_fixed_5deg_mount_v0_1.stl
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

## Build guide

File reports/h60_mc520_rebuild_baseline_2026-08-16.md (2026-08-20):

# H60 + MC520 重建与公开仓库统一报告

> 日期：2026-08-16
> 更新：2026-08-20
> 结论：公开数字基线已统一；实物、上电和运动仍未放行。

## 已解决的主要矛盾

- 主要入口从 STM32 + WSDC2412D + JGB37-520 切换为 H60 V3.7 + MC520P56。
- 旧 83-85mm 轮、CPR、三层 CAD 和 Stage D/E 只保留历史意义；新平台采用 65mm 轮、新 CAD 和 H0-H8。
- Mid360 与 Orin 均使用独立电源支路，不从 H60 供电。
- 主保险、主开关与 H60/Orin/Mid360 三条支路保护保留；支路额定由线束、端子和实测冻结。
- 当前不安装独立急停按钮、继电器、急停 GPIO、Keyes 或 ACS712；主开关只作人工整车断电，不称急停。
- H60 必须实现默认 DISARMED、显式 ARM、STOP/DISARM、命令超时、IWDG、异常撤 PWM 和重启后禁止自动恢复运动。
- H60 PC0 采 VIN；当前没有车载电流遥测。外部仪表只产生台架测试证据。
- H60 的 TVS、驱动内部保护和 VIN ADC 都不能替代主保险、支路保护或实测验收。
- 新增 H60/Orin 任一侧掉电时的 UART 反供电验证门。
- 上一平台照片、接线和硬件台账转入历史归档，不再作为当前接线或运动准入依据。

## 未关闭项

到货和版本、支路额定、AT8236 限流与 MC520 负载能力、回生浪涌、UART 反供电、Mid360 低输入与峰值、H60 运动控制固件、机械试装、编码器标定和落地运动均需实测。

H60 失电后 PC0 VIN 遥测也会消失，首版没有独立电池/SOC 遥测。

## 当前公开入口

- [H60 当前电源、运动约束与采样边界](../docs/02_architecture/h60_power_motion_sampling_boundary.md)
- [H60 电源接线基线](../hardware/wiring/h60_power_wiring_v0_2.md)
- [H60 运动控制固件要求](../firmware/h60_motion_control_firmware_requirements_v0_2.md)
- [H0-H8 重建验收计划](../docs/06_testing/p2_h60_mc520_rebuild_acceptance_plan_2026-08-16.md)

## 公开参考

- OpenCTR H60：https://www.xtark.cn/product/show.php?itemid=7
- MC520：https://www.xtark.cn/product/show.php?itemid=25
- Livox Mid360：https://www.livoxtech.com/mid-360/specs
- NVIDIA Jetson Orin 载板规范：https://developer.nvidia.com/downloads/assets/embedded/secure/jetson/orin_nano/docs/jetson_orin_nano_devkit_carrier_board_specification_sp.pdf

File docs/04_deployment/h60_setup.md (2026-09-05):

# OpenCTR H60 部署入口

> 文档状态：正式入口 / 运动锁定固件无电机 bring-up 已完成 / 动力部署未放行
> 适用版本：OpenCTR H60 V3.7 / STM32F407VET6
> 依据：当前 H60 + MC520 公开架构、固件要求与验收计划

## 当前已确认

1. H60 作为四路 MC520P56 电机/编码器的底层控制器。
2. 目标通信为 Orin NX UART；永久接线前必须关闭 H60 掉电反供电风险。
3. 板载 VIN ADC `PC0` 承接主电池电压监测；外置 Keyes 模块不装。
4. H60 J2/J3 不为 Orin 或 Mid360 供电。
5. H60 板载开关保持 ON；外置主开关管理整车电源。当前没有独立急停或继电器，主开关不得称为急停。
6. Project0 自有 `v0.1.1-safe-bringup` 已在 MA-MD 全空条件下完成刷写、官方验证、独立完整回读和冷启动通信检查；固件仍编译期锁死运动输出。

VIN ADC 只在 H60 上电时可用。H60 支路故障、维护断电或整车断电后，Orin 不再获得该电压遥测；它用于上电期间的母线电压观测，功能范围不含持续 SOC 监测。当前没有车载电流采样。

## 部署顺序与当前进度

1. H0：已完成部分实物与不上电核对，但完整到货、针序、资料和阶段记录尚未关闭，H0 仍为 `NOT RUN`。
2. 已建立不依赖不明 EXE/预编译 HEX 的可复现固件构建路径，并记录工具版本、命令、产物散列和厂家完整 Flash 回滚件。
3. 已在不接电机条件下完成 `v0.1.1` 冷启动、VIN 原始采样、串口遥测、STOP 和 ARM 运动锁检查；这不是限流电源、低压轨或 VIN 多点校准验收。
4. `firmware/h60_motion_control_firmware_requirements_v0_2.md` 已部分实现；PWM、闭环速度、斜坡、反转死区、完整故障注入和标定仍待后续门。
5. 完成 UART 反供电保护后，再进行 Orin 双向通信和故障注入。
6. 按 H0-H8 计划逐级进入电机、动力和落地测试。

## 当前未完成与边界

H60 V3.7、四组 MC520 和九根线的到货身份/线序已由恢复的历史原图、用户现场清单、逐线测量和原厂资料关闭，`H0 = PASS`；Project0 `v0.1.1` 也已完成无电机安全 bring-up。H1/H3-H8 仍未通过，H2 仅为当前最小三支路 PARTIAL；Orin 侧仍是旧 STM32 文本桥，UART 单侧掉电反供电、带载输出、编码器方向/CPR、PWM/闭环、温升、回生、停车距离和完整故障注入均未关闭。厂商示例、无电机 bring-up 和空载万用表 `0 V` 观察都不能自动关闭这些门，也不放行接电机或运动。

公开产品入口：https://www.xtark.cn/product/show.php?itemid=7 。H0 已以到货 V3.7 实物丝印、4×MC520 铭牌、九根线直通记录和随附资料关闭；后续电气与运动功能仍按 H2-H7 真实测量为准。

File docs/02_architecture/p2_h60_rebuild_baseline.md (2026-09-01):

# P2 H60 + MC520 当前实现基线

> 文档状态：正式 / 当前实现覆盖层
> 决策来源：当前公开架构与安全边界
> 适用范围：P2 重建、采购确认、CAD、接线、固件和验收
> 状态边界：最终架构不变；2026-09-01 起 Orin 送修，临时执行 H60-only 子轨；运动仍未通过

## 1. 当前与历史边界

H60 新车采用 OpenCTR H60 V3.7、四套 MC520P56、Orin NX、Mid360 和 D435。旧文档中的 STM32、WSDC2412D、JGB37-520、Keyes、ACS712、急停/继电器、CTRL-001、六路保险盒和三层底盘属于上一实车基线；其历史记录仍有效，但不定义当前重建方案。

### 1.1 Orin 送修期间的临时覆盖

2026-09-01 的电气冒烟事件后，Orin NX/C1902 已交由专业维修。维修完成并重新通过独立电源、启动和安全检查前，Orin、Mid360、D435、ROS2、上位机判断与数据上传链全部暂停。P2 临时只推进 H60 能独立承接的本地运动安全、前进/后退/停止和无 Orin 手柄接口可行性。

这不是架构改版：最终职责表和下述拓扑继续有效。当前 H60 固件仍为运动锁定状态，手柄原路径依赖 Orin USB/ROS2；新的直接手柄路径为 `TBD / NOT RUN`，不得在接口与失联停车验证前接入或运动。

## 2. 当前拓扑

```text
3S battery -> 25A main fuse -> main switch -> fused distribution
                                              +-> H60 branch -> H60 -> 4 x MC520P56
                                              +-> Orin DC/DC -> Orin NX -> D435 / gamepad
                                              +-> Mid360 DC/DC -> Mid360

Orin NX <---------------- versioned, protected UART ----------------> H60
Mid360 <-------------------------- 100BASE-TX ----------------------> Orin NX
D435 <------------------------------ USB 3 -------------------------> Orin NX
```

当前没有独立急停按钮、急停继电器、急停 GPIO 或车载电流采样。主开关用于整车断电，不得称为急停。

## 3. 职责划分

| 实体 | 当前职责 | 明确不承担 |
| --- | --- | --- |
| Orin NX | ROS2、感知、定位、导航、任务、手动/自动仲裁、显式 ARM、日志 | 电机实时 PWM；在链路丢失后替 H60 本地停车 |
| H60 | 四路编码器、四路驱动、速度闭环、命令超时、IWDG、故障撤 PWM、VIN ADC | Orin/Mid360 供电；车载电流遥测 |
| COMP-001 | Orin 独立 12V 供电 | Mid360/H60 供电 |
| SENS-009 | Mid360 独立 12V 供电 | Orin/H60 供电 |
| 主开关 | 人工断开整车电源 | 独立急停或认证安全功能 |

## 4. 旧实现映射

| 旧实现 | 当前实现 | 处理方式 |
| --- | --- | --- |
| STM32F407 控制板 | OpenCTR H60 V3.7 | 旧部署/固件/测试只读保留；新固件单独实现 |
| 2 × WSDC2412D | H60 4 × AT8236 集成驱动 | 旧接线、温升和额定结论不可迁移 |
| 4 × JGB37-520 + 83–85 mm 轮 | 4 × MC520P56 + 65 mm 轮 | 旧 CPR、轮径、速度和载荷不可迁移 |
| Keyes 外置电压采样 | H60 `PC0` VIN ADC | 多点校准后生效 |
| ACS712 总电流采样 | 不安装 | 当前没有车载电流采样；外部仪表只作调试 |
| 急停按钮/继电器/NO 反馈 | 不安装 | 历史记录保留；当前运动约束见 DEC-047 |
| CTRL-001 5V 支路 | 不纳入当前 | H60 内部低压供电，其他负载独立支路 |
| 三层冻结 CAD | 用户新两层 CAD | 旧 CAD 只作历史参考 |

## 5. 运动状态机与处置

| 事件 | H60 要求 | Orin 要求 | 人工边界 |
| --- | --- | --- | --- |
| 上电/复位 | `BOOT -> DISARMED`，PWM=0，清旧状态 | 启动并保持未授权 | 先完成静止检查 |
| 新的人工 ARM | 自检、心跳、故障和命令新鲜度通过才使能 | 新会话、输入回中、新鲜命令 | 明确进入测试门 |
| UART 超时/Orin 故障 | 本地超时撤 PWM、清控制状态 | 停止发布并记录故障 | 必要时关闭主开关 |
| H60 看门狗/异常 | 异常入口先撤 PWM，再复位或保持故障 | 识别链路丢失并锁止运动 | 回到不上电检查 |
| 主开关断开 | 整车失电 | 不适用 | 仅作人工断电，不称急停 |

## 6. 采样

- 车载采样：H60 `PC0` VIN ADC 电压，多点校准后上报。
- 不具备：车载电流采样、H60 失电后的持续电池观测、长期 SOC 估计。
- H60 驱动内部电流调节/过流动作不等同于电流遥测。

## 7. 当前阻断项

1. 实物、版本、线材、端子和支路保护尚未现场冻结。
2. UART 任一侧掉电反供电尚未关闭。
3. H60 `v0.1.1-safe-bringup` 已实现运动锁定条件下的 ARM 拒绝、STOP/DISARM、250 ms 超时、IWDG、异常前置安全输出和版本化二进制协议，并完成无电机刷写/回读/冷启动检查；Orin 侧二进制桥、会话规划、`motion_ready`、双重运动配置门和默认 0 轮目标上限已完成离线实现。Orin ROS2/H60 实机联调、A-D 实物映射、H6 上限、PWM/闭环、UART 单侧掉电、协议恢复和 H5 完整硬件故障注入尚未完成。
4. 单路/四路持续能力、温升、回生和主开关断开瞬态尚未测试。
5. VIN ADC 尚未完成多点校准。
6. 新 CAD 尚未完成实物试装、质量/重心、维护空间和线束路径验证。
7. Mid360 支路的低电量、冷启动峰值和动力瞬态稳定性尚未验证。
8. 当前无独立硬件急停，落地运动必须使用更严格的低能量、人工监看和场地隔离条件，并由用户单独授权。

任一阻断项未关闭时，不得把数字基线解释为可上电、可落地运动或可无人运行。

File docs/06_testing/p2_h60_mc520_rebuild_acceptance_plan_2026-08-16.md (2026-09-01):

# P2 H60 + MC520 重建验收计划

> 当前修订：2026-09-01 / H60 无动力安全基线与 H60-only 临时子轨
> 状态：H0 为 PASS；H2/H3/H5 为 PARTIAL；H1/H4/H6-H8 未通过。Orin NX/C1902 已送修，当前不开放接电机、PWM或运动
> 原则：每一门只开放下一门，不跨门，不以旧平台结果替代当前实测

## 1. 门总览

| 门 | 目标 | 最小证据 | 当前状态 |
| --- | --- | --- | --- |
| H0 | 到货与版本 | H60 V3.7、4×MC520P56、线束/支架/联轴器/65 mm 轮的数量、外观、标签、针序和资料版本 | PASS |
| H1 | 机械试装 | 两层结构、孔位、公差、紧固、轮系、连接器、风道、线束与拆卸包络、质量/重心 | NOT RUN |
| H2 | 不上电电气 | 主保险、主开关、三支路保护、极性、线径、端子、共地、绝缘与轻拉 | PARTIAL：当前最小支路路径已有受限证据；最终线束待回归 |
| H3 | 分支上电 | 分别验证 H60、Orin、Mid360 的输入/输出、冷启动、压降与温升 | PARTIAL：H60 无电机上电/遥测和 Mid360 独立支路部分通过；Orin 送修、最终配置待验 |
| H4 | 单侧掉电与通信 | H60/Orin 任一侧掉电不反供电；UART 协议恢复保持 DISARMED | NOT RUN |
| H5 | 固件约束 | 默认失能、显式 ARM、超时、IWDG、异常撤 PWM、CRC/序号/长度故障注入 | PARTIAL：运动锁定固件与离线协议/仲裁通过；完整实机故障注入待验 |
| H6 | 单通道与编码器 | 四路逐一方向、计数边沿、CPR、速度、斜坡、反转零输出与停车 | NOT RUN |
| H7 | 四轮架空与电源动态 | 四路模式、温升、压降、回生/刹车/反转波形、VIN ADC 校准、通信断联停车 | NOT RUN |
| H8 | 落地低速 | 受控区域、0.1–0.2 m/s 起步、人工持续监看、停车距离、热、直线/转向与接管 | NOT RUN |

### Orin 送修期间 H60-only 临时子轨

| 子门 | 目标 | 状态 |
| --- | --- | --- |
| M0 | 隔离 Orin/传感器，冻结 H60-only 拓扑与安全边界 | DIGITAL BASELINE |
| M1 | H60 本地运动固件设计与离线验证 | NOT RUN |
| M2 | 可靠架空下逐路确认电机方向、编码器与停车 | NOT RUN |
| M3 | 四轮架空前进/后退/停止与断联停车 | NOT RUN |
| M4 | 受控场地最低速落地前进/后退/停止 | NOT RUN |
| G0 | 不依赖 Orin 的手柄接口、实现与失联停车 | TBD / NOT RUN |

该子轨不改变最终 Orin + H60 架构，也不关闭 H4-H8 总门。既定 USB 手柄链依赖 Orin；不得假定 H60 具备 USB HID 主机能力。

## 2. 当前硬件边界

当前 H60 新车不安装独立急停按钮、继电器、急停 GPIO、Keyes 或 ACS712。车载采样只有 H60 `PC0` VIN ADC 电压；电流仅能由外部仪表在台架中临时测量。主开关用于整车断电，不得记作急停验收。

没有独立急停意味着 H8 必须额外满足：空旷平坦区域、远离楼梯口/天井边缘/电梯口/排水槽、最低速度与加速度、短距离、操作者与主开关直接可达、必要的非导电机械后备约束，以及用户当次明确授权。

## 3. H0–H2：不上电阶段

1. H0 逐件拍摄标签、接口和损伤，核对 H60 版本、MC520 数量/型号/减速比/编码器线序和所有拟复用件状态。
2. H1 对 28 个 STEP 对应实物进行孔位、板厚、平面度、打印尺寸、连接器、散热、线束和拆卸路径试装；实物通过状态以该轮检查结果为准。
3. H2 在电池拆除条件下核对完整电源树。不得残留旧急停线圈、继电器、ACS712 或旧平台路号。
4. 记录每条支路的线径、端子、保险候选与选择依据；不凭经验直接增大保险。

## 4. H3–H4：低能量供电与通信

1. 首次 H60 上电不接电机，优先使用限流电源；分别记录启动电流、输入电压、低压轨和温升。
2. Orin 与 Mid360 分支独立验证，确认 DC-DC 极性、12 V 输出、冷启动和短时稳定性。
3. 分别制造 H60 断电/Orin 上电和 Orin 断电/H60 上电，测量对侧电源轨、UART 电平和反灌电流。
4. 验证 H60/Orin 任一侧重启、UART 断开和恢复后均保持 `DISARMED`，旧会话、旧序号和缓存命令无效。
5. 永久运动线束和 H5/H6 的进入条件是 H4 通过。

## 5. H5：固件故障注入

依据 `firmware/h60_motion_control_firmware_requirements_v0_2.md`，至少覆盖：上电/复位零 PWM、ARM 条件、输入回中、STOP/DISARM、命令超时、心跳丢失、CRC 错误、过长帧、序号回退、Orin 重启、IWDG 和异常入口。每次失败都写入 P2 日志，修复必须指向真实源码与回归结果。

## 6. H6–H7：架空运动

1. 车辆可靠架空，轮周净空，先单通道后四通道，使用最低有效 PWM/速度与短脉冲。
2. 四路分别确定 Motor ±、A/B、计数符号、计数边沿和 CPR，禁止迁移旧 JGB 数据。
3. 验证正反转、左右转、停止、斜坡、反转零输出、通信断联停车和人工接管。
4. 使用外部仪表测量单路到四路的电流、压降与温升；这些数据属于台架测量，车辆当前没有电流采样通道。
5. 用合适的探头记录刹车、反转和主开关断开时的 H60 VIN 波形。无可信波形、温升或停车证据则 H7 不通过。
6. 完成 VIN ADC 多点校准并记录误差。

## 7. H8：落地低速

H8 必须由用户在当次现场状态下明确授权。前置条件包括 H0–H7 全部通过、结构与线束固定、场地隔离、人员和障碍清空、主开关可直接触达、操作者持续目视、初始速度不高于 `0.1–0.2 m/s` 且加速度保守。

按短距离前进、停车、后退、转向、通信断联停车、人工接管的顺序逐项执行。任何异常立即停止命令并关闭主开关，回到断电检查；不得靠近高风险区域，不得无人测试。

## 8. 记录与完成条件

- 每门记录硬件/软件版本、日期、条件、命令、原始结果、失败、修复和证据路径；
- 结果应记录硬件/固件版本、条件、原始数据与证据文件；
- P2 只有在 H0–H8、真实代码、通信、里程计、接管和文档记录全部通过后才完成，并在用户批准后发布 v1.1；
- 旧平台 Stage D/E、CPR、轮径、动力和急停记录不自动关闭本计划任何门。

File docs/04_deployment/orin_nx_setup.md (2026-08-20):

# Orin NX 环境搭建

> **当前补充**：Orin 环境继续沿用；原 Orin↔STM32 UART 结论不能直接迁移。新 Orin↔H60 链路需重新验证电平、协议和 H60 掉电时反供电。

## P1.4-0 Orin NX 实机基线记录

记录日期：2026-06-03

本节记录 P1.4 工程环境搭建开始前的 Orin NX 实机基线。后续安装 ROS2、传感器驱动、SLAM / Navigation 相关依赖前，应优先以本节作为环境起点。

### 1. 硬件与载板背景

| 项目 | 当前记录 |
| --- | --- |
| 计算模块 | Jetson Orin NX 16GB |
| 载板 / 套件 | Seeed reComputer Orin NX 16GB + J401 载板镜像 |
| 镜像标识 | `mfi_recomputer-orin-nx-16g-j401-6.2-36.4.3-2026-02-05.tar.gz` |
| 载板功耗边界 | 当前 J401 载板应保持在官方 25W 级运行边界内。JetPack 6.2 理论上可能暴露 Orin NX Super / 40W 能力，但本项目在当前非 Super 版 J401 载板上不启用 40W / MAXN SUPER。 |

### 2. 操作系统基线

| 项目 | 当前记录 |
| --- | --- |
| 主机名 | `project0-orin-nx` |
| 操作系统 | Ubuntu 22.04.5 LTS |
| 系统代号 | `jammy` |
| 架构 | `aarch64` / `arm64` |
| L4T 版本 | R36.4.3 |
| 内核版本 | `5.15.148-tegra` |
| `/etc/nv_tegra_release` 分支 | `R36.4.3` |

说明：当前 Seeed 镜像中，`dpkg-query --show nvidia-l4t-core` 未找到匹配的软件包。因此本文中的 L4T 版本从 `/etc/nv_tegra_release` 记录。

### 3. 资源基线

| 项目 | 当前记录 |
| --- | --- |
| 根分区磁盘 | 总计 457G，已用 20G，可用 418G，使用率 5% |
| 内存 | 总计 15Gi，基线检查时约使用 1.3Gi |
| Swap | 总计 7.6Gi |

### 4. 功耗模式基线

| 项目 | 当前记录 |
| --- | --- |
| 当前 `nvpmodel` 模式 | `25W` |
| `nvpmodel -q` 显示的模式 ID | `3` |
| 项目规则 | 除非后续载板 / 供电决策明确改变边界，否则当前 J401 载板上以 25W 作为最高运行模式。 |

### 5. 网络与远程访问基线

| 项目 | 当前记录 |
| --- | --- |
| 当前活动网络接口 | `wlp1p1s0` |
| 当前 IPv4 地址 | `<orin-nx-ip>/<prefix>` |
| SSH 服务 | `active (running)` |
| SSH 端口 | `22` |
| SSH 用户 | `<ssh-user>` |
| 远程访问命令 | `ssh user@<orin-nx-ip>` |

当前 IP 地址由 Wi-Fi 分配，后续可能变化。如果 SSH 连接失败，在 Orin NX 上用以下命令检查当前地址：

```bash
hostname -I
ip -br addr
```

### 6. ROS2 安装前已完成的本机可用性修复

开始 ROS2 安装前，已处理以下本机可用性问题：

1. Orin NX 启动问题定位为拆除外接按钮接线后残留的外部电源按钮 / 排针组件影响。
2. Firefox Snap 启动失败问题已通过重启 Snap 相关服务解决。
3. GNOME Terminal 启动失败问题定位为 locale 配置不完整；已将 `LANG` 恢复为 `zh_CN.UTF-8`。
4. 恢复过程中安装 / 使用了 `xterm` 作为备用终端。
5. 已确认浏览器和必要网络访问可用于后续开发资料查询。

### 7. 基线复查命令

在进行较大的环境变更前，可使用以下命令复查当前基线：

```bash
hostname
lsb_release -a
cat /etc/nv_tegra_release
uname -a
df -h
free -h
sudo nvpmodel -q
ip -br addr
systemctl status ssh --no-pager
locale
```

## P1.4 收束复查与网络排障记录

记录日期：2026-06-04

本节记录 P1.4 工程环境搭建收束复查前出现的一次 Orin NX 网络临时异常，以及恢复后的环境复查结果。它是部署与排障记录；网络长期稳定性及 ROS2 / STM32 正式功能仍待后续验证。

### 1. SSH 连接异常现象

Windows 侧连接 Orin NX 时出现：

```text
ssh <orin-nx-ip> 超时
ping <orin-nx-ip> 显示 Destination host unreachable
```

在 Orin NX 本机检查时，`ssh.service` 仍为 `active`。因此本次现象不判断为 SSH 服务损坏，而优先按网络链路异常处理。

### 2. Orin NX 本机排查线索

本机排查中观察到以下现象：

| 项目 | 当前记录 |
| --- | --- |
| SSH 服务 | `active` |
| Wi-Fi 状态 | `nmcli device status` 显示 Wi-Fi 断开 |
| Wi-Fi 扫描 | `nmcli device wifi list` 扫不到 Wi-Fi |
| Wi-Fi 发射功率线索 | `iw dev` 曾显示 `txpower -100.00 dBm` |
| rfkill 状态 | `Soft blocked: no` / `Hard blocked: no` |

当前解释：SSH 服务没有坏，主要异常在线路访问前的 Wi-Fi 模块 / 驱动状态。`rfkill` 未显示软 / 硬阻塞，因此本次不按用户主动禁用 Wi-Fi 处理。

### 3. 恢复结果

执行：

```bash
sudo reboot
```

重启后 Wi-Fi 恢复。恢复后的状态记录为：

| 项目 | 当前记录 |
| --- | --- |
| Wi-Fi 接口 | `wlP1p1s0` |
| 接口状态 | `UP` |
| IPv4 地址 | `<orin-nx-ip>/<prefix>` |
| Wi-Fi 连接 | `<wifi-ssid>` |
| 发射功率 | `txpower 7.00 dBm` |

结论：本次 Windows 侧 SSH 超时不是 SSH 服务损坏，而是 Orin NX Wi-Fi 模块 / 驱动临时异常；重启后网络恢复。后续如再次出现相同现象，应优先在 Orin NX 本机复查 `ip -br addr`、`nmcli device status`、`nmcli device wifi list`、`iw dev` 和 `rfkill`，再判断是否需要进一步处理无线网卡驱动或供电稳定性。

### 4. P1.4 环境收束复查结果

网络恢复后，用户按 P1.4 收束复查建议确认以下内容均正常：

1. Orin NX 可通过 SSH 继续访问；
2. Orin NX 当前 ROS2 Humble 环境变量可用；
3. `~/project0_ros2_ws` 工作区可继续执行 `colcon build`；
4. 最小测试包 `p0_bringup` 可被 ROS2 package 索引识别；
5. STM32 工具链、设备枚举、最小编译复验和 ST-LINK 通道边界记录维持当前已记录状态。

当前收束口径：

1. P1.4-0 Orin NX 实机基线已记录；
2. P1.4-1 ROS2 Humble 基础环境已完成最小通信验证；
3. P1.4-2 ROS2 工作区骨架已完成 `colcon build` 验证；
4. P1.4-3 STM32 工具链与设备识别已记录；
5. P1.4-4 STM32 最小工程编译链路已复验；
6. P1.4-5 STM32CubeProgrammer ST-LINK 通道边界已确认。

以上完成工程环境的最小验证链路。FAST-LIO2、Nav2、Livox 驱动、RealSense 驱动、正式 ROS2 功能包、正式 STM32 固件、STM32 烧录 / 调试、ROS2-STM32 通信、电机 / 电驱 / 主电池接线和 P2 装配验证当时均未完成。

## P1.4 远程开发与调试方案当前口径

记录日期：2026-06-04

当前 P1.4 最小收束中，远程访问已经确认到 SSH 可用：

```bash
ssh user@<orin-nx-ip>
```

该结果确认 Orin NX 可按 headless + SSH 方式继续开发和排障。完整远程调试方案尚未冻结；VSCode Remote、远程桌面、文件同步、图形界面转发、串口调试协同和多终端工作流按真实开发需要补充。

当前口径：

1. SSH 是已确认的最小远程访问方案；
2. 完整远程调试方案不作为 P2 前置条件；
3. 如果后续 P2-P6 实机开发中 SSH 不足以支撑调试，再补充远程开发记录。

## C1902 V1.1 载板 40W 综合压力测试

记录日期：2026-06-14

Orin NX 16GB 在 C1902 V1.1 载板上完成 20 分钟 CPU + GPU + 内存综合压力测试：

| 项目 | 结果 |
| --- | --- |
| 功耗模式 | `40W` / mode `4` |
| CPU / GPU 压力程序退出状态 | 均为 `0` |
| 最高 `tj / cpu` | `80.468C` |
| 最高 GPU 温度 | `76.25C` |
| 最高 `VDD_IN` | 约 `26.1W` |
| 过温停止阈值 | `85C`，未触发 |

测试期间未观察到重启、SSH 断连、进程异常退出或卡死。该结果只覆盖未接入相机、雷达和整车动力系统时的计算侧综合压力，不等同于真实业务负载或整车装车验收。

完整记录见 `../../reports/orin_nx_c1902_40w_mixed_stress_test_2026-06-14.md`。

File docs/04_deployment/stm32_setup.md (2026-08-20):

# STM32 开发环境搭建

> **历史记录**：本文仅描述上一平台。当前目标控制器是 H60 V3.7，部署入口见 [h60_setup.md](h60_setup.md)。

## P1.4-3 STM32 开发环境盘点与基础识别记录

记录日期：2026-06-03

本节记录 Windows 主机上 STM32 基础开发工具链与 USB 设备识别的初步盘点结果。当前阶段只确认工具链和设备枚举，不写正式固件、不烧录正式程序、不接电机、不接电驱、不接主电池，也不连接 Orin NX UART。

### 1. 当前目标边界

P1.4-3 当前只做以下事项：

1. 检查 Windows 上是否已有 STM32CubeIDE；
2. 检查 Windows 上是否已有 STM32CubeProgrammer；
3. 检查 Windows 是否能识别 STM32F407VET6 核心板 / 开发板 V5.5 相关 USB 设备；
4. 初步区分 CMSIS-DAP / USB Serial / COM 口 / ST-Link 类设备；
5. 记录工具链与设备识别状态。

当前不做以下事项：

1. 不创建正式 STM32 固件工程；
2. 不烧录正式程序；
3. 不接电机、电驱或主电池；
4. 不接 Orin NX UART；
5. 底盘控制、ROS2-STM32 通信和电气联调均不在本节完成范围内。

### 2. STM32CubeIDE 检查结果

先检查常见默认路径：

```powershell
Test-Path "C:\ST\STM32CubeIDE"
```

本次输出：

```text
False
```

该结果只说明 `C:\ST\STM32CubeIDE` 这个常见路径不存在，不代表 STM32CubeIDE 一定没有安装。

随后检查 Windows 已安装程序登记项，确认：

| 项目 | 当前记录 |
| --- | --- |
| 软件 | STMicroelectronics STM32CubeIDE |
| 版本 | `1.19.0` |
| 安装路径 | 本地安装目录 |

结论：Windows 主机上已安装 STM32CubeIDE 1.19.0。

补充状态：用户确认 STM32CubeIDE 可以打开；更新过程中出现过信任来源 / 信任构件确认窗口，随后 CubeIDE 回到主界面，`Progress` 视图显示 `No operations to display at this time`。当前已确认 IDE 可启动并进入稳定主界面。

2026-06-04 补充：用户随后将 STM32CubeIDE 更新到 `2.1.1`，About 窗口显示：

| 项目 | 当前记录 |
| --- | --- |
| 软件 | STM32CubeIDE |
| 版本 | `2.1.1` |
| Build | `28236_20260312_0043 (UTC)` |

界面入口检查：用户确认 `File -> New` 菜单中存在 `STM32 Project` 入口。当前仅确认工程创建入口可见，尚未创建正式 STM32 工程。

2026-06-04 补充：STM32CubeIDE 更新到 `2.1.1` 后，新建工程入口行为与 `1.19.0` 有变化。为避免误选 CMake / Empty Project 路径，本次升级后复验改用独立 STM32CubeMX 生成 STM32CubeIDE 工程，再导入 STM32CubeIDE 编译。

### 3. STM32CubeProgrammer 检查结果

先检查常见默认路径：

```powershell
Test-Path "C:\Program Files\STMicroelectronics\STM32Cube\STM32CubeProgrammer"
```

本次输出：

```text
False
```

初次检查时，在 Windows 已安装程序登记项中按 `STM32CubeProgrammer` / `CubeProgrammer` 关键字查询，未发现匹配项。

随后从 STMicroelectronics 官方渠道下载并安装 Windows 64 位安装器：

```text
SetupSTM32CubeProgrammer_win64.exe
```

安装后在 Windows 已安装程序登记项中确认：

| 项目 | 当前记录 |
| --- | --- |
| 软件 | STM32CubeProgrammer |
| 版本 | `2.22.0` |

用户确认 STM32CubeProgrammer 可正常打开。

结论：Windows 主机上已安装 STM32CubeProgrammer 2.22.0，并已确认可启动。当前仅确认工具链可用，不连接目标板、不擦除、不下载、不烧录正式程序。

### 4. STMicroelectronics 驱动登记项

Windows 已安装程序登记项中发现以下 STMicroelectronics 驱动包：

| 项目 | 当前记录 |
| --- | --- |
| STLink WinUSB 驱动包 | `Windows Driver Package - STMicroelectronics (WinUSB) STLinkWinUSB (06/08/2017 2.01)` |
| ST usbser 驱动包 | `Windows Driver Package - STMicroelectronics (usbser) Ports (06/08/2017 2.01)` |

结论：Windows 主机上已有 STMicroelectronics 相关 WinUSB 与 usbser 驱动包登记记录。

### 5. Windows 设备识别检查结果

原计划使用：

```powershell
Get-PnpDevice | Where-Object { $_.FriendlyName -match "STM|ST-Link|STLink|CMSIS|DAP|USB Serial|COM" } | Format-Table -AutoSize
```

但在当前终端会话中该命令返回：

```text
Get-PnpDevice : 拒绝访问
```

这表示当前会话无权通过该接口读取 PnP 设备列表，不表示 STM32 开发板、CMSIS-DAP、ST-Link 或串口设备损坏。

随后使用 `pnputil` 读取设备枚举，发现以下相关条目：

| 设备线索 | 当前记录 |
| --- | --- |
| CMSIS-DAP 相关 USB 设备 | `USB\VID_0416&PID_5051\CMSIS-DAP` |
| 设备描述 | `USB Composite Device` |
| 当前状态 | `Started` |
| 驱动 | `usb.inf` |

串口类设备中发现以下与 USB 串口相关的条目：

| 设备线索 | 当前记录 |
| --- | --- |
| USB 串行设备 | `USB\VID_0416&PID_5051&MI_01\6&1929203c&0&0001` |
| 设备描述 | `USB 串行设备 (COM8)` |
| 当前状态 | `Started` |
| 驱动 | `usbser.inf` |

同时系统中还存在多个蓝牙 RFCOMM 串口，例如 `COM3`、`COM4`、`COM5`、`COM7`、`COM10`、`COM11`。这些是蓝牙链接上的标准串行端口，不应直接当作 STM32 开发板 USB 转串口来使用。

当前解释：

1. Windows 曾经枚举到 VID/PID 为 `0416:5051` 的 CMSIS-DAP / USB 串口复合设备；
2. 复查时 CMSIS-DAP 复合 USB 设备状态为 `Started`，说明 Windows 当前已识别到板载 CMSIS-DAP 设备；
3. 复查时 USB 串行设备状态为 `Started`，并枚举为 `COM8`；
4. 当前可以确认 USB 线具备数据传输能力，开发板的 CMSIS-DAP 与 USB 串口枚举基础可用。

### 6. 建议复查命令与解读

插入 STM32F407VET6 核心板 / 开发板 V5.5 后，建议先只复查设备识别，不打开烧录流程。

```powershell
pnputil /enum-devices /instanceid "USB\VID_0416&PID_5051\CMSIS-DAP"
```

这条命令做什么：查看 Windows 记录的 CMSIS-DAP 复合 USB 设备详情。

为什么现在运行：确认开发板板载调试器是否被 Windows 识别为当前连接设备。

正常输出怎么看：如果 `Status` 显示 `Started`，通常表示设备当前已连接并由 Windows 驱动接管。

异常输出怎么看：如果 `Status` 仍是 `Disconnected`，说明 Windows 当前没有把它识别为正在连接；如果找不到实例，说明设备枚举记录不存在或 VID/PID 不匹配。

```powershell
pnputil /enum-devices /class Ports
```

这条命令做什么：列出 Windows 当前登记的串口类设备。

为什么现在运行：确认开发板的 USB 转串口是否枚举为 `COMx`。

正常输出怎么看：应重点寻找非蓝牙的 `USB 串行设备 (COMx)`，并查看它的 `Status` 是否为 `Started`。

异常输出怎么看：如果只看到蓝牙串口，或者 USB 串行设备为 `Disconnected`，说明当前还没有确认开发板串口在线。

### 7. 当前结论

P1.4-3 已完成初步工具链与设备识别盘点：

1. STM32CubeIDE 已确认安装，版本为 `1.19.0`；
2. STM32CubeIDE 已确认可启动并进入稳定主界面；
3. `File -> New` 菜单中已确认存在 `STM32 Project` 入口，但尚未创建正式工程；
4. STM32CubeProgrammer 已确认安装，版本为 `2.22.0`，并可正常打开；
5. Windows 已有 STMicroelectronics WinUSB / usbser 驱动包登记记录；
6. Windows 已确认识别到 CMSIS-DAP 复合 USB 设备，状态为 `Started`；
7. Windows 已确认识别到 USB 串行设备 `COM8`，状态为 `Started`；
8. 当前阶段仍停留在工具链与设备识别，不进入正式固件、烧录、接线或电气联调。

## P1.4-4 STM32 最小工程创建与编译验证记录

记录日期：2026-06-03

本节记录 STM32CubeIDE 中基于 STM32F407VET6 的最小工程创建、代码生成和编译验证结果。当前阶段只验证 IDE、固件库包和编译工具链可用，不烧录程序、不连接目标板、不执行调试、不接电机、电驱、主电池或 Orin NX UART。

### 1. 工程创建目标

本次最小工程用于验证：

1. STM32CubeIDE 可选择 `STM32F407VET6` 目标芯片；
2. STM32Cube F4 固件库包可被 CubeIDE 识别；
3. CubeIDE 可生成基础 STM32Cube 工程；
4. ARM GCC 工具链可完成最小工程编译；
5. 生成结果只作为工具链验证，不作为正式底盘控制固件。

### 2. 固件库包补齐过程

首次创建 STM32Cube 工程时，CubeIDE 提示缺少必要 firmware package，无法完成工程创建：

```text
Code generation could not be done most probably because the necessary firmware package is missing.
Not able to complete STM32Cube project creation.
```

CubeIDE 在线登录 / 下载过程中出现过网络连接失败和 `api_config.json (Not available)` 提示。因此本次改用 STMicroelectronics 官方下载的本地压缩包导入 STM32Cube F4 固件库。

已下载并使用以下本地包：

| 文件 | 作用 |
| --- | --- |
| `<Windows 用户目录>\\Downloads\stm32cubef4-v1-28-0.zip` | STM32CubeF4 主包 |
| `<Windows 用户目录>\\Downloads\stm32cubef4-v1-28-3.zip` | STM32CubeF4 补丁包 |

导入补丁包时，CubeIDE 曾提示缺少：

```text
stm32cube_fw_f4_v1280.zip
```

处理方式：将已下载的 `stm32cubef4-v1-28-0.zip` 复制到 CubeIDE Repository，并命名为补丁导入器要求的文件名：

```powershell
Copy-Item -LiteralPath "<Windows 用户目录>\\Downloads\stm32cubef4-v1-28-0.zip" -Destination "<STM32Cube Repository>\stm32cube_fw_f4_v1280.zip"
```

随后确认 Repository 中存在：

```text
<STM32Cube Repository>\STM32Cube_FW_F4_V1.28.0
<STM32Cube Repository>\STM32Cube_FW_F4_V1.28.3
```

### 3. 首次工程创建异常

首次尝试创建工程时，工程名疑似前置空格导致生成了异常本地临时工程目录。

该目录中生成了部分 `Core`、`Drivers` 和 `main.c`，但缺少 CubeIDE C/C++ 工程识别所需的 `.cproject`，导致 `Build Project` 不可用。该目录只作为异常过程记录，不作为本次验证通过工程。

另有不带前置空格的残留目录，内容不完整，仅作为失败残留记录，不作为本次验证通过工程。

### 4. 最小工程编译验证结果

随后用户重新创建了一个干净的最小工程。当前通过编译验证的工程目录为本地临时工程目录。

该工程目录中已确认存在：

1. `.project`
2. `.cproject`
3. `.mxproject`
4. `1.ioc`
5. `Core/`
6. `Drivers/`
7. `Debug/`
8. `STM32F407VETX_FLASH.ld`
9. `STM32F407VETX_RAM.ld`

CubeIDE Console 中显示已调用 ARM GCC 工具链，例如：

```text
arm-none-eabi-gcc
arm-none-eabi-size 1.elf
arm-none-eabi-objdump -h -S 1.elf > "1.list"
```

编译结果：

```text
Build Finished. 0 errors, 0 warnings.
```

构建耗时记录：

```text
took 44s.398ms
```

生成的目标文件名：

```text
1.elf
```

### 5. 当前结论

P1.4-4 STM32 最小工程创建与编译验证已完成：

1. STM32Cube F4 固件库已补齐到 `V1.28.3`；
2. STM32CubeIDE 可创建 STM32F407VETx 最小工程；
3. 本地临时工程已完成编译；
4. 编译结果为 `0 errors, 0 warnings`；
5. 当前验证只证明 STM32CubeIDE、STM32Cube F4 固件库和 ARM GCC 编译链路可用；
6. 当前未烧录程序、未连接目标板、未调试运行、未接电机、电驱、主电池或 Orin NX UART；
7. 该工程只是最小编译验证工程，不是项目0正式 STM32 固件工程。

### 6. STM32CubeIDE 2.1.1 升级后复验

记录日期：2026-06-04

用户将 STM32CubeIDE 更新到 `2.1.1` 后，使用独立 STM32CubeMX `6.17.0` 重新生成最小 STM32F407VETx 工程，并导入 STM32CubeIDE 进行编译复验。

本次复验工具链记录：

| 项目 | 当前记录 |
| --- | --- |
| STM32CubeIDE | `2.1.1` |
| STM32CubeIDE Build | `28236_20260312_0043 (UTC)` |
| STM32CubeMX | `6.17.0` |
| 固件库 | `STM32Cube FW_F4 V1.28.3` |
| 目标芯片 | `STM32F407VETx` |
| 工程语言 | `C` |
| Toolchain / IDE | `STM32CubeIDE` |

CubeMX 代码生成结果：

```text
The Code is successfully generated under:
<local STM32 workspace>/p14_4_f407_build_check_v2
```

随后在 STM32CubeIDE 中通过 `File -> Open Projects from File System...` 导入该工程。当前通过升级后复验的工程目录为本地临时工程目录。

该目录中已确认存在：

1. `.project`
2. `.cproject`
3. `.mxproject`
4. `p14_4_f407_build_check_v2.ioc`
5. `Core/`
6. `Drivers/`
7. `STM32F407VETX_FLASH.ld`
8. `STM32F407VETX_RAM.ld`

STM32CubeIDE Console 编译记录显示：

```text
Build of configuration Debug for project p14_4_f407_build_check_v2
make -j24 all
Finished building target: p14_4_f407_build_check_v2.elf
```

生成目标文件：

```text
p14_4_f407_build_check_v2.elf
```

编译尺寸记录：

```text
text    data    bss     dec     hex     filename
4728    12      1572    6312    18a8    p14_4_f407_build_check_v2.elf
```

编译结果：

```text
Build Finished. 0 errors, 0 warnings. (took 41s.23ms)
```

复验结论：

1. STM32CubeIDE 已更新到 `2.1.1`，并可导入 CubeMX 生成的 STM32CubeIDE 工程；
2. STM32CubeMX `6.17.0` 可为 `STM32F407VETx` 生成最小工程；
3. STM32Cube F4 固件库 `V1.28.3` 可被 CubeMX / CubeIDE 使用；
4. 本地临时工程已在 STM32CubeIDE `2.1.1` 中完成编译；
5. 编译结果为 `0 errors, 0 warnings`；
6. 本次复验只证明 STM32 工具链、固件库和最小工程编译链路可用；
7. 当前仍未烧录程序、未连接目标板、未调试运行、未接电机、电驱、主电池或 Orin NX UART；
8. 该工程只是最小编译复验工程，不是项目0正式 STM32 固件工程。

## P1.4-5 STM32 下载 / 调试接口边界确认记录

记录日期：2026-06-04

本节记录 STM32CubeProgrammer 对当前 STM32F407VET6 核心板 / 开发板 V5.5 的 ST-LINK 通道识别结果。当前阶段只确认下载 / 调试工具边界，不擦除、不下载、不烧录、不调试运行、不接电机、电驱、主电池或 Orin NX UART。

### 1. 当前目标边界

P1.4-5 当前只做以下事项：

1. 打开 STM32CubeProgrammer；
2. 选择 `ST-LINK` 连接方式；
3. 刷新 ST-LINK 设备列表；
4. 记录 CubeProgrammer 是否能发现 ST-LINK 类调试器；
5. 将该结果与 Windows 侧 CMSIS-DAP / USB Serial 识别结果区分记录。

当前不做以下事项：

1. 不点击 `Connect` 尝试连接目标芯片；
2. 不点击 `Erase`；
3. 不点击 `Download`；
4. 不写入 Flash；
5. 不执行调试运行；
6. 本节结束时 STM32 仍未进入下载、烧录、运行或底盘控制联调状态。

### 2. STM32CubeProgrammer ST-LINK 通道检查结果

检查工具：

| 项目 | 当前记录 |
| --- | --- |
| 软件 | STM32CubeProgrammer |
| API 版本 | `v2.22.0` |
| 平台 | `Windows-64Bits` |

用户在 STM32CubeProgrammer 中选择 `ST-LINK` 连接方式并刷新设备列表后，界面显示：

| 项目 | 当前记录 |
| --- | --- |
| 连接方式 | `ST-LINK` |
| Serial number | `No ST-LINK...` |
| 状态 | `Not connected` |
| Port | `SWD` |
| Target information | 未显示目标板 / Device / CPU 信息 |

### 3. 当前解释

该结果与 P1.4-3 中 Windows 设备枚举记录一致：

1. Windows 侧已识别当前板载 USB 复合设备为 CMSIS-DAP / USB Serial 相关设备；
2. STM32CubeProgrammer 的 `ST-LINK` 通道未发现 ST-LINK 类调试器；
3. 当前现象不等于 STM32 开发板损坏，也不等于 USB 线不可用；
4. 当前只能确认：这块板在现有 USB 连接下，不表现为 STM32CubeProgrammer 可直接识别的 ST-LINK 设备；
5. 后续如需下载 / 调试，应在对应阶段再确认可行路径，例如外接 ST-LINK，或评估 CMSIS-DAP / OpenOCD 等路径；当前不提前展开正式下载 / 调试流程。

### 4. 当前结论

P1.4-5 STM32 下载 / 调试接口边界确认已完成：

1. STM32CubeProgrammer `2.22.0` 可正常打开；
2. `ST-LINK` 连接方式下未发现 ST-LINK 设备，界面显示 `No ST-LINK...`；
3. 当前结果与 Windows 侧 CMSIS-DAP / USB Serial 枚举结果一致；
4. 当前未连接目标芯片、未擦除、未下载、未烧录、未调试运行；
5. STM32CubeProgrammer 的 ST-LINK 通道当前不是可用下载链路；
6. `No ST-LINK...` 记录为工具链边界，现有证据不足以判定板卡故障。

## P2 CMSIS-DAP / OpenOCD 与控制板故障状态

记录日期：2026-06-17

后续 P2 实测已确认 WCH-Link / CMSIS-DAP 可由 OpenOCD 识别，因此下载 / 调试路径不再只依赖 STM32CubeProgrammer 的 ST-LINK 通道。

但原 STM32 控制板随后出现板载 3.3V 供电故障：

1. 5V 输入正常；
2. 3.3V 仅为零点几伏；
3. `RESET / NRST = 0V`；
4. 外接控制线拔除后未发现 5V / 3.3V 对地硬短路；
5. 当前不能继续 SWD 目标连接、USART3 烧录或动力测试。

替换板当时需要按单板供电、车载 5V、SWD、USART3 和 Orin NX 收包的顺序重新验收。技术摘要见 `../../hardware/archive/wiring_legacy_pre_h60_2026-08-20/p2_stm32_power_fault_summary_2026-06-17.md`。

## P2 替换板、UART、编码器与工程迁移状态

记录日期：2026-07-13

后续 P2 实测已完成以下闭环：

1. 替换 STM32 控制板完成基础供电、CMSIS-DAP / OpenOCD 和目标芯片识别；
2. USART3 三线通信链路恢复，Orin NX 可读取 STM32 周期输出；
3. STM32 可周期输出 `P0_STM32_UART_OK` 和四路编码器计数摘要；
4. Orin NX 向 STM32 发送测试文本后，STM32 可回传 ACK；
5. 四路编码器在第 4 路动力保险空置、人工手动转轮、UART 读数条件下均已产生有效计数；
6. 左前 `LF` 替换电机并重新压紧编码器供电 / 地线后，低功率手动转轮复验通过；
7. 旧开发主机上的当前项目 STM32 工程已迁移到新开发主机，并完成构建检查；
8. 车上 STM32 flash 已完成只读备份，active 固件前缀与迁移工程产物和新开发主机构建产物一致。

当前公开边界：

1. 该结果说明 STM32 工程恢复、构建和备份路径成立；
2. 正式底盘控制协议、通信中断停车、无新指令停车、编码器方向符号归一化和里程计当时仍未完成；
3. 该结果不开放主动动力、悬空动力或落地低速运动；
4. 后续若需要烧录，仍需重新确认目标固件、flash 备份、供电状态、第 4 路动力保险状态、急停和回滚方案。

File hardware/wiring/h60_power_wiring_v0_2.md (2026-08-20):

# H60 重建版电源接线基线 v0.2

> 状态：正式设计输入 / 尚未实装
> 依据：当前 H60 + MC520 数字基线与公开验收门
> 边界：本文不是现场已接线记录；任何物理接线前必须断电、拆除电池并按实物针序复核

## 1. 当前电源树

```text
PWR-001 3S battery (+)
-> PWR-006 25A main fuse
-> PWR-003 external main switch
-> fused distribution positive input

Branch A: H60 fuse -> H60 J1 (+)
Branch B: Orin fuse -> COMP-001 IN+ -> 12V OUT -> C1902 DC5525 center (+)
Branch C: Mid360 fuse -> SENS-009 IN+ -> 12V OUT -> Mid360 (+)

Common negative bus:
battery (-), H60 J1 (-), COMP-001 IN-, SENS-009 IN-
```

当前只保留主保险、主开关和 H60/Orin/Mid360 三条支路保护。支路保险额定值必须由线径、端子、器件输入范围以及稳态/峰值测量冻结，不得直接照搬旧平台路号或旧四支路建议值。

## 2. 当前明确不接入的器件

- 独立急停按钮及其 NC/NO 触点；
- 急停继电器/接触器和线圈支路；
- Orin 急停反馈 GPIO；
- Keyes 外置电压模块；
- ACS712 或其他车载电流采样模块；
- 旧 STM32、WSDC、CTRL-001 和六路保险盒既有路号。

旧平台器件可以保留为备件或历史证据，但不得接入 H60 新车当前线束。主开关用于整车断电，不得标记为急停。

## 3. H60 与四套电机

四套 MC520P56 使用配套 XH2.54 六芯线分别接入 H60 的四路电机/编码器端口。电机端目标定义为：

| Pin | 信号 |
| ---: | --- |
| 1 | Motor - |
| 2 | Encoder VCC |
| 3 | Encoder A |
| 4 | Encoder B |
| 5 | Encoder GND |
| 6 | Motor + |

装车前必须对每根线完成针序、通断、Motor ±、Encoder VCC/GND 和 A/B 核对。安装方向带来的符号差异通过低能量、单通道、架空测试确定，不允许只凭线色猜测。

## 4. Orin–H60 UART

基本连接为 `TX <-> RX`、`RX <-> TX`、`GND <-> GND`。H60 或 Orin 可能因支路故障、维护、开关顺序或启动时序形成单侧上电，因此永久连接前必须：

1. 分别验证 H60 断电/Orin 上电和 Orin 断电/H60 上电；
2. 测量对方电源轨与 UART 引脚是否被抬高，并记录反灌电流；
3. 必要时采用任一侧掉电时输出高阻的双电源缓冲或数字隔离；
4. 验证任一侧重启或链路恢复后都保持 `DISARMED`，不能恢复旧命令。

反供电门未关闭前，不得把直连 UART 制作为永久运动线束。

## 5. 电压采样

当前车载采样只有 H60 `PC0` 板载 VIN ADC。它必须经过多点校准，记录原始 ADC、参考仪表电压、拟合参数、误差和校准版本。该通道测量 H60 上电期间的支路 VIN；H60 失电期间没有独立电池观测通道。

当前没有车载电流采样。外部钳形表或合规功率分析仪可以在台架调试时测量电流，但不属于车载功能，也不能产生持续电流遥测声明。

## 6. 上电前检查

- 电池、25A 主保险、主开关、分配节点和三条支路与图一致；
- 各支路保险、线径、端子、极性和器件输入范围可追溯；
- H60、Orin、Mid360 没有经错误端口互相供电；
- 无继电器线圈、急停触点、ACS712 或旧采样小板残留在当前链路；
- UART 单侧掉电门已通过，或在该门前保持断开；
- 所有线束具备标识、绝缘、应力释放和裸露导体检查；
- 首次 H60 上电优先使用限流电源且不接电机；
- 首次电机测试车辆可靠架空、轮周净空、低占空比、人工持续监看，主开关可直接触达。

本文是数字接线基线；实物接线、上电和运动分别由 H2-H8 验收记录确认。

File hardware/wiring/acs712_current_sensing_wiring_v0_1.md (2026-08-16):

# ACS712-30A 电流采样接线记录 v0.1

> **历史记录**：ACS712 不纳入 H60 重建首版；动力验收先使用外部钳表或串联功率计。

## 1. 文件作用

本文档记录 Project0 P2 装配阶段 `CTRL-005 ACS712-30A` 动力支路总电流检测模块与 STM32 之间的接线方式，重点说明 ACS712 信号侧分压滤波小板的材料、洞洞板布局、焊接节点和检查方法。

本文档不替代 既有设计记录、正式底盘控制固件、ADC 标定记录或 P2 电流采样测试记录。

## 2. 接入边界

ACS712-30A 大电流端串入动力支路正极：

```text
PWR-MOT-003 继电器 87
-> CTRL-005 ACS712-30A 电流传感器模块
-> 动力分线端子
-> 两块电机驱动板 P+
```

ACS712 信号侧接入 STM32：

```text
ACS712 V -> 控制支路 5V
ACS712 G -> STM32 GND / 控制侧 GND
ACS712 S -> 分压滤波小板 -> STM32 PA1 / ADC
```

重要边界：

```text
ACS712 S 不得直接接 STM32 ADC。
ACS712 S 也不得接 3.3V。
```

原因：ACS712-30A 在 5V 供电时，零电流输出约 `2.5V`，正向大电流时可能高于 STM32 ADC 的 `0V-3.3V` 输入范围。因此必须先分压，再接 STM32 ADC。

当前分配口径：

| 信号 | STM32 引脚 | 说明 |
|---|---|---|
| 动力支路电流采样 | `PA1` | ACS712 S 经分压滤波后接入 |
| 主电池电压采样 | `PA0` | 预留给 `CTRL-004` 电压检测模块 |

## 3. 分压滤波电路

首版分压滤波电路：

```text
ACS712 S ---- 12k ----+---- STM32 PA1
                      |
                     22k
                      |
                     GND

STM32 PA1 点 ---- 0.1uF ---- GND
```

分压比例约为：

```text
22k / (12k + 22k) ~= 0.647
```

估算电压：

| 状态 | ACS712 S 原输出 | STM32 PA1 分压点 |
|---|---:|---:|
| 0A | 约 `2.50V` | 约 `1.62V` |
| +30A | 约 `4.48V` | 约 `2.90V` |
| -30A | 约 `0.52V` | 约 `0.34V` |

`0.1uF` 电容用于简单 RC 滤波。若现场暂时没有电容，可以先只焊 `12k + 22k` 分压，电容后补；但分压不应省略。

## 4. 材料清单

| 材料 | 数量 | 要求 |
|---|---:|---|
| 剪好的洞洞板 | 1 小块 | 建议至少 `3 列 x 4 行` |
| `12kΩ` 插件电阻 | 1 | 1/4W，1% 或 5% 均可 |
| `22kΩ` 插件电阻 | 1 | 1/4W，1% 或 5% 均可 |
| `104` 陶瓷电容 | 1 | `0.1uF`，50V 可用，无正负极 |
| 2.54mm 排针 / 杜邦公针 | 3 个信号位 | `S_IN`、`PA1_OUT`、`GND` |
| 小信号线 / 杜邦线 | 若干 | 连接 ACS712 与 STM32 |
| 热缩管 / 绝缘材料 | 若干 | 包覆小板和焊点 |
| 扎带 / 双面胶 / 绝缘固定件 | 若干 | 固定小板，避免焊点受力 |

电阻和 `104` 陶瓷电容均无正负极。

## 5. 三列四行洞洞板布局

### 5.1 坐标定义

洞洞板正面看，定义 `3 列 x 4 行`：

```text
A1   B1   C1
A2   B2   C2
A3   B3   C3
A4   B4   C4
```

节点定义：

```text
A 列 = S_IN
B 列 = ADC_NODE / PA1_OUT
C 列 = GND
```

洞洞板默认每个孔彼此不连通，因此焊接时必须在背面把同一列连成节点：

```text
A1-A2-A3-A4 连成 S_IN
B1-B2-B3-B4 连成 ADC_NODE
C1-C2-C3-C4 连成 GND
```

建议用剪下来的电阻脚或短导线做背面跳线，不建议新手只靠大面积焊锡桥。

### 5.2 元件插孔表

| 元件 / 线 | 第 1 脚 | 第 2 脚 | 说明 |
|---|---|---|---|
| `12kΩ` 电阻 | `A1` | `B1` | ACS712 S 到 ADC 节点的上分压电阻 |
| `22kΩ` 电阻 | `B2` | `C2` | ADC 节点到 GND 的下分压电阻 |
| `104` 电容 | `B3` | `C3` | ADC 节点到 GND 的滤波电容 |
| ACS712 S 输入排针 / 线 | `A4` | 无 | 标记为 `S_IN` |
| STM32 PA1 输出排针 / 线 | `B4` | 无 | 标记为 `PA1_OUT` |
| GND 排针 / 线 | `C4` | 无 | 标记为 `GND` |

正面逻辑：

```text
A1 -- 12k -- B1
B2 -- 22k -- C2
B3 -- 104 -- C3
A4 = S_IN
B4 = PA1_OUT
C4 = GND
```

背面跳线：

```text
A1-A2-A3-A4
B1-B2-B3-B4
C1-C2-C3-C4
```

完成后，等效连接为：

```text
ACS712 S
-> A4
-> A 列跳线
-> A1
-> 12k
-> B1
-> B 列跳线
-> B4
-> STM32 PA1
```

同时：

```text
B 列 ADC_NODE -> 22k -> C 列 GND
B 列 ADC_NODE -> 104 -> C 列 GND
```

## 6. 接口建议

建议小板上使用排针，方便和现有杜邦母头连接：

| 接口 | 排针 | 用途 |
|---|---|---|
| ACS 输入侧 | `1P` 公针 | `S_IN`，接 ACS712 `S / OUT` |
| STM32 输出侧 | `2P` 公针 | `PA1_OUT + GND`，接 STM32 `PA1 + GND` |

也可以使用 `3P` 公针：

```text
S_IN | PA1_OUT | GND
```

若使用 `3P` 公针，必须在线束两端清楚标识，避免把 ACS712 S、STM32 PA1 和 GND 插错。

## 7. 焊接步骤

1. 剪一小块洞洞板，至少保留 `3 列 x 4 行`。
2. 按坐标插入 `12kΩ`：`A1 -> B1`。
3. 按坐标插入 `22kΩ`：`B2 -> C2`。
4. 按坐标插入 `104` 电容：`B3 -> C3`。
5. 插入或焊接 `S_IN`：`A4`。
6. 插入或焊接 `PA1_OUT`：`B4`。
7. 插入或焊接 `GND`：`C4`。
8. 背面用短导线 / 剪下来的元件脚连通 `A1-A2-A3-A4`。
9. 背面连通 `B1-B2-B3-B4`。
10. 背面连通 `C1-C2-C3-C4`。
11. 检查背面焊点，确保 A、B、C 三列之间没有意外短路。

`22kΩ` 和 `104` 电容是并联关系，不需要叠在一起焊；它们分别占用 `B2-C2` 和 `B3-C3`，但两端通过 B 列和 C 列跳线接到同一对节点。

## 8. 万用表检查

焊完后先不上电，使用欧姆档检查：

| 测量点 | 预期 |
|---|---|
| `A4` 到 `B4` | 约 `12kΩ` |
| `B4` 到 `C4` | 约 `22kΩ` |
| `A4` 到 `C4` | 约 `34kΩ` |
| A 列任意两个孔 | 接近 `0Ω` |
| B 列任意两个孔 | 接近 `0Ω` |
| C 列任意两个孔 | 接近 `0Ω` |
| A 列到 C 列 | 不应接近 `0Ω` |
| B 列到 C 列 | 不应接近 `0Ω`，应约 `22kΩ` |

如出现接近 `0Ω` 的异常短路，不得上电。

## 9. 上电验证

首次上电时，先不要把 `PA1_OUT` 接入 STM32，只接：

```text
ACS712 V -> 5V
ACS712 G -> GND
ACS712 S -> 小板 S_IN
小板 GND -> GND
```

上电后用万用表测量：

| 测量点 | 预期 |
|---|---|
| ACS712 S / 小板 `S_IN` 对 GND | 零电流附近约 `2.5V` |
| 小板 `PA1_OUT` 对 GND | 零电流附近约 `1.6V` |

确认 `PA1_OUT` 电压低于 `3.3V` 后，断电，再连接：

```text
小板 PA1_OUT -> STM32 PA1
小板 GND -> STM32 GND
```

## 10. 固定要求

分压滤波小板不得悬空晃动。完成检查后，应至少满足：

1. 小板背面焊点不接触底盘、螺丝、保险盒金属件或其他裸线。
2. 小板用热缩管、绝缘胶带或绝缘外壳包覆。
3. 小板通过扎带、双面胶或绝缘固定件固定在第二层线束附近。
4. `S_IN`、`PA1_OUT`、`GND` 三根线都有标签或颜色区分。
5. 线束移动时，焊点不承受拉力。

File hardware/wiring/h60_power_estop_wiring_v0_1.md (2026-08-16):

# H60 电源与急停接线基线 v0.1

> 状态：设计输入，尚未实装。接线前必须断开电池并按实物针序复核。

## 电源树

```text
3S battery (+)
-> 25A main fuse
-> external main switch
-> fused distribution

A: H60 fuse (start 10A) -> relay 30 -> relay 87 -> H60 (+)
B: Orin fuse (start 10A) -> Orin DC/DC -> 12V -> carrier board
C: Mid360 fuse (start 3A) -> Mid360 buck-boost -> 12V -> Mid360
D: coil fuse 1A -> estop NC -> relay 86

Common negative: battery, H60, both DC/DC inputs, relay 85
```

起始保险值只用于台架验证，最终不得超过线材、端子和设备允许值。

## 继电器与急停

| 端子 | 连接 |
| --- | --- |
| 30 | H60 支路保险输出 |
| 87 | H60 正极 |
| 85 | 共负极 |
| 86 | 1A 保险后经急停 NC 的线圈正极 |
| 87a | 不接并绝缘 |

如继电器带续流二极管，必须保持 86 为正、85 为负。NC 只控制线圈；按下急停后 H60 失电，Orin 与 Mid360 不断电。

## NO 状态反馈

```text
Orin 3.3V -> external 4.7-10k pull-up -> signal node
signal node -> estop NO -> Orin GND
signal node -> about 1k series resistor -> GPIO input
```

NO 是无源干接点，禁止接 12V。软件应消抖并锁存急停。单个 NO + 上拉不能区分“急停释放”和“反馈线断开”，因此硬件停车不能依赖该反馈。最终 GPIO、GND 和 pinmux 必须按载板资料和实物方向确认。

## UART

只连接 TX↔RX、RX↔TX 和共地。Orin 上电而 H60 断电时必须测量反灌；正式线束需使用在任一侧掉电时输出高阻、不会形成旁路的缓冲或隔离方案。此门关闭前不得固定直连 UART。

## 上电前

确认主/支路保险、极性、NC/NO、30/87、85/86、二极管方向、绝缘、应力释放和线束标识。首次 H60 上电不接电机并优先使用限流电源；首次电机测试车辆架空、低占空、轮周净空且有人直接监看。

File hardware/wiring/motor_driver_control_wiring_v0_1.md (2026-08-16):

# 电驱控制线接线与验证记录 v0.1

> **历史记录**：本文只适用于上一 STM32 + WSDC2412D 平台，禁止用于 H60/MC520 接线。

## 1. 文件作用

本文档记录 Project0 P2 装配阶段两块 WSDC2412D-V3.0 双通道直流有刷电机驱动器与 STM32F407VET6 控制板之间的控制线接线表、颜色分配、固件安全默认状态和当前验证结果。

本文档只覆盖电驱控制端 `VCC / GND / PWM / INA / INB`，不覆盖电驱动力端 `P+ / P-`、电机输出大电流线、编码器线、采样模块或 Orin NX 通信。

## 2. 硬件边界

| 项目 | 当前值 |
|---|---|
| STM32 控制板 | STM32F407VET6 核心板 / 开发板 V5.5 |
| 电驱 | WAYNESTARK WSDC2412D-V3.0，2 块 |
| 电驱控制电平 | `3.3V` |
| 控制端接口 | CN1，2.54mm 2x5 双排针 |
| 线材/端子 | 现有杜邦母对母线 / 22AWG 级别小信号线口径 |
| 当前状态 | 控制线接入、安全初始化验证、四个单电机短脉冲测试、悬空同侧联动和四轮联动测试已完成；原 STM32 故障前最后一次已知烧录为安全初始化，但当前 3.3V 与 NRST 异常，不能确认固件仍在运行 |

## 3. 数据手册结论

数据手册：

`hardware/reference_docs/drive/PWR-MOT-004_WSDC2412D-V3_0_datasheet.pdf`

关键结论：

1. 控制端 `VCC` 兼容 `3.3V` / `5V`；
2. 控制端 `VCC` 必须与控制信号高电平幅值相同；
3. `PWM / INA / INB` 输入信号悬空时为高电平；
4. `INA=H, INB=H` 为脱机；
5. `INA=L, INB=L` 为制动；
6. `INA=L, INB=H` 为正转；
7. `INA=H, INB=L` 为反转。

因此当前安全初始化不采用 `INA=0, INB=0` 作为默认状态，而采用：

```text
PWM = 0
INA = 1
INB = 1
电驱状态 = 脱机
```

## 4. 电机通道映射

| 电驱 | 通道 | 电机 |
|---|---|---|
| DRV-L | CH1 / M1 | 左前 LF |
| DRV-L | CH2 / M2 | 左后 LR |
| DRV-R | CH1 / M1 | 右后 RR |
| DRV-R | CH2 / M2 | 右前 RF |

说明：右侧当前映射按实物走线便利性固定为 `RF=M2`、`RR=M1`，与早期假设 `RF=M1`、`RR=M2` 不同。后续固件和测试应以本文当前映射为准。

## 5. 颜色分配

| 信号类型 | 颜色 | 说明 |
|---|---|---|
| VCC / 3.3V | 红色 | 每块电驱控制端接一根 |
| GND | 黑色 | 每块电驱控制端接一根 |
| PWM | 偏黄色 | 四个通道各一根 |
| INA | 紫色 | 四个通道各一根 |
| INB | 绿色 | 四个通道各一根 |

## 6. 完整接线表

| 电机 / 电驱 | 电驱接口 | STM32 引脚 | 默认状态 | 说明 | 颜色 |
|---|---|---|---|---|---|
| 左侧电驱公共 | DRV-L `VCC` | STM32 `3.3V` | `3.3V` | 左电驱控制逻辑供电 | 红色 |
| 左侧电驱公共 | DRV-L `GND` | STM32 `GND` | `0V` | 左电驱控制地 | 黑色 |
| 左前 LF | DRV-L `PWM1` | `PB6` | `0V` | 左前 PWM；后续可作为 TIM4_CH1 | 偏黄色 |
| 左前 LF | DRV-L `INA1` | `PD0` | `3.3V` | 左前方向 A | 紫色 |
| 左前 LF | DRV-L `INB1` | `PD1` | `3.3V` | 左前方向 B | 绿色 |
| 左后 LR | DRV-L `PWM2` | `PB7` | `0V` | 左后 PWM；后续可作为 TIM4_CH2 | 偏黄色 |
| 左后 LR | DRV-L `INA2` | `PD2` | `3.3V` | 左后方向 A | 紫色 |
| 左后 LR | DRV-L `INB2` | `PD3` | `3.3V` | 左后方向 B | 绿色 |
| 右侧电驱公共 | DRV-R `VCC` | STM32 `3.3V` | `3.3V` | 右电驱控制逻辑供电 | 红色 |
| 右侧电驱公共 | DRV-R `GND` | STM32 `GND` | `0V` | 右电驱控制地 | 黑色 |
| 右后 RR | DRV-R `PWM1` | `PB8` | `0V` | 右后 PWM；后续可作为 TIM4_CH3 | 偏黄色 |
| 右后 RR | DRV-R `INA1` | `PD4` | `3.3V` | 右后方向 A | 紫色 |
| 右后 RR | DRV-R `INB1` | `PD5` | `3.3V` | 右后方向 B | 绿色 |
| 右前 RF | DRV-R `PWM2` | `PB9` | `0V` | 右前 PWM；后续可作为 TIM4_CH4 | 偏黄色 |
| 右前 RF | DRV-R `INA2` | `PD6` | `3.3V` | 右前方向 A | 紫色 |
| 右前 RF | DRV-R `INB2` | `PD7` | `3.3V` | 右前方向 B | 绿色 |

## 7. 已完成检查

### 7.1 不上电通断 / 短路检查

| 检查项 | 结果 |
|---|---|
| STM32 `3.3V` 与 `GND` | 蜂鸣档不响，曾显示约 `0.731V` 压降 |
| 电驱控制端 `VCC` 与 `GND` | 蜂鸣档不响，曾显示约 `0.419V` 压降 |
| 控制线端到端导通 | 用户确认正常 |
| 相邻信号短路 | 未发现异常 |

### 7.2 数据手册确认前的观测

| 条件 | 观测 | 后续解释 |
|---|---|---|
| 电驱控制端 `VCC` 接 STM32 `3.3V`，STM32 未安全初始化 | 多数 `PWM / INA / INB` 稳定约 `2.9-3.3V` | 数据手册说明输入悬空为高电平 |
| 断开两块电驱控制端 `VCC` | `PWM` 约 `0V`，其他约 `1V` | 未供电/悬空状态，不作为逻辑判断 |

### 7.3 安全初始化后实测

实测条件：

1. 主电池未接；
2. 电驱动力端 `P+ / P-` 未接；
3. STM32 安全初始化固件已烧录并处于运行状态；
4. 两块电驱控制端 `VCC` 红线已接 STM32 `3.3V`；
5. 两块电驱控制端 `GND` 已接 STM32 `GND`。

实测结果：

| 测点 | 目标 | 结果 |
|---|---|---|
| 两块电驱 `VCC` | 约 `3.3V` | 符合 |
| 两块电驱 `GND` | `0V` | 符合 |
| 两块电驱 `PWM1 / PWM2` | 约 `0V` | 符合 |
| 两块电驱 `INA / INB` | 约 `3.3V` | 符合 |

当前结论：

```text
控制线接入和 STM32 安全初始化验证通过。
当前电驱控制状态为 PWM=0, INA=H, INB=H，即脱机。
```

### 7.4 单电机低占空比短脉冲测试

共同测试条件：

1. 一次只测试一个电机；
2. 四个轮子悬空；
3. 用户全程人工看守；
4. 急停机械安装仍未完成，因此只允许短时低占空比测试；
5. 测试固件为临时固件，不作为正式底盘控制固件；
6. 每次测试后烧回安全初始化状态。

实测电机输出接线：

| 电机 | 电驱通道 | 电机动力线 |
|---|---|---|
| 左前 LF | DRV-L `M1 / CH1` | 红线 -> `M1A`；白线 -> `M1B` |
| 左后 LR | DRV-L `M2 / CH2` | 红线 -> `M2A`；白线 -> `M2B` |
| 右前 RF | DRV-R `M2 / CH2` | 红线 -> `M2A`；白线 -> `M2B` |
| 右后 RR | DRV-R `M1 / CH1` | 红线 -> `M1A`；白线 -> `M1B` |

阶段诊断：

| 检查项 | 结果 |
|---|---|
| `PB6` 普通 GPIO 高电平输出，保持约 `10s` | STM32 端和 DRV-L `PWM1` 端均正常 |
| `TIM4_CH1` / `PB6` 约 50% PWM 输出 | DRV-L `PWM1` 端正常 |
| `PB7` 普通 GPIO 高电平输出，保持约 `10s` | DRV-L `PWM2` 端正常 |
| `PB8` 普通 GPIO 高电平输出，保持约 `10s` | DRV-R `PWM1` 端正常 |
| DRV-R `INA1 / INB1` 方向诊断 | `INA1` 可拉低到约 `0.18V`，`INB1` 约 `3.3V`，符合方向控制预期 |

短脉冲测试行为：

| 项目 | 设置 |
|---|---|
| PWM 通道 | 目标电机对应 `TIM4_CH1` 到 `TIM4_CH4` 中的一路 |
| 比较值 | `8` |
| 估算占空比 | 约 `14%` 到 `15%` |
| 持续时间 | 约 `500ms` |
| 方向状态 | `INA=L, INB=H` |
| 测试后状态 | `PWM=0, INA=H, INB=H` |

测试结果：

| 电机 | 实际通道 | 结果 |
|---|---|---|
| `LF` | DRV-L `M1 / CH1` | 通过 |
| `LR` | DRV-L `M2 / CH2` | 通过 |
| `RF` | DRV-R `M2 / CH2` | 通过 |
| `RR` | DRV-R `M1 / CH1` | 通过 |

边界：

```text
当前只验证四个电机能分别在低占空比短脉冲下转动。
不表示方向一致性、编码器读取、整车落地运动或正式控制固件已完成。
```

### 7.5 主输入保险熔断与端子修复

`LR` 测试准备过程中曾出现疑似打火 / 噼啪声，后续定位到：

1. 电源开关输入端端子在移动第三层底板时松脱；
2. 主输入 25A ATO / ATC 保险丝熔断，保险丝本体测得 `OL`；
3. 用户更换电源开关输入端端子；
4. 用户更换同规格 25A ATO / ATC 主输入保险丝；
5. 修复后断电检查、短时上电观察和左右电驱动力输入恢复正常。

该问题说明主输入保险起到了异常保护作用，也说明线束防拉扯和端子固定仍需后续整理。

### 7.6 悬空同侧联动与四轮联动测试

在四个单电机低占空比短脉冲测试通过后，继续进行了悬空同侧联动和四轮联动测试。

初始联动时曾沿用单电机阶段参数：

| 项目 | 初始值 |
|---|---|
| 比较值 | `8` |
| 估算占空比 | 约 `14%` 到 `15%` |
| 持续时间 | 约 `500ms` |

当时现象为：

1. `LF` 在左侧联动中不转；
2. `LR` 可转；
3. 右侧两个轮子可转，但方向与左侧相反。

后续针对 `LF` 执行了以下诊断：

1. 左电驱 `P+ / P-` 供电、左侧支路保险和 `LF` 动力线通断复核通过；
2. 仅控制端上电时，`PB6 -> DRV-L PWM1` 诊断测得约 `3.26V`，控制线通过；
3. `PD0 / PD1 -> DRV-L INA1 / INB1` 方向诊断通过；
4. `PB6` 作为普通 GPIO 直拉高的极短脉冲可驱动 `LF` 起转；
5. `TIM4_CH1` 走正常 PWM 路径、接近 `100%` 占空比的极短脉冲同样可驱动 `LF` 起转。

阶段判断：

```text
LF 问题不是硬件损坏，也不是 TIM4_CH1 故障。
更符合 LF 在联动场景下的低占空比起转门槛高于 compare=8 的保守参数。
```

最终联动测试参数调整为：

| 项目 | 最终值 |
|---|---|
| 比较值 | `20` |
| 估算占空比 | 约 `36%` |
| 持续时间 | 约 `200ms` |
| 启动等待 | 约 `5s` |
| 分阶段间隔 | 约 `8s` |

方向补偿口径：

1. 左侧保持 `INA=L, INB=H`；
2. 右侧在当前测试固件中采用 `INA=H, INB=L` 反向补偿，以符合“从车尾向车头看，朝车头方向为正方向”的定义。

最终结果：

| 阶段 | 结果 | 方向 |
|---|---|---|
| 左侧 `LF + LR` | 通过 | 均朝正方向 |
| 右侧 `RF + RR` | 通过 | 反向补偿后均朝正方向 |
| 四轮同时短脉冲 | 通过 | 四轮均朝正方向 |

测试结束后，STM32 已重新烧回安全初始化状态。

## 8. 未完成项

1. 尚未进行电机编码器接线与读取验证；
2. 尚未进行整车落地运动测试；
3. 尚未进行线束固定、抗振、防拉扯最终整理；
4. 急停按钮机械安装和急停继电器切断链路仍未完成，后续动力测试必须保持短时受控；
5. 临时测试固件不作为常驻安全固件，测试结束后需烧回安全初始化状态。

## 9. 下一步

本轮四个单电机短脉冲测试、悬空同侧联动和四轮联动测试已完成。测试收尾时原 STM32 曾烧回安全初始化；2026-06-17 后续确认原板 3.3V 与 NRST 异常，因此该历史收尾动作不代表故障板当前仍在运行或维持安全输出。

后续若进入编码器验证、急停闭环或整车落地动力测试，应重新满足：

1. 轮子悬空；
2. 只开放计划测试的电机通道；
3. 先确认电驱 `P+ / P-` 极性、保险路径和电机输出端；
4. 启动默认保持 `PWM=0, INA=H, INB=H`；
5. 正式固件起步参数应考虑 `LF` 联动场景下的最低有效占空比，不能直接默认沿用 `compare=8`；
6. 观察编码器方向、噪声、电驱指示灯、线束发热和异常保护；
7. 急停链路完成前不做无人看守或落地动力测试；
8. 固件必须采用当前右侧实物映射：`RF = DRV-R M2 / PB9 / PD6 / PD7`，`RR = DRV-R M1 / PB8 / PD4 / PD5`；
9. 若继续沿用当前方向定义，则右侧需保留软件反向补偿或重新改线后再验证。

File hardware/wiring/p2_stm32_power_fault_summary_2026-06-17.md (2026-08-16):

# P2 STM32 3.3V 供电故障摘要

> **历史记录**：该故障只解释上一 STM32 平台，不是当前 H60 状态。

## 1. 故障现象

2026-06-17，在继续 USART3 最小通信测试前，WCH-Link / CMSIS-DAP 已能被 OpenOCD 识别，但无法读取 STM32 目标芯片 ID。

隔离检查确认：

1. 车上控制支路 5V 输入正常；
2. 外接控制线拔除后，5V / 3.3V 对地未发现硬短路；
3. 板载 3.3V 仅为零点几伏；
4. `RESET / NRST = 0V`；
5. Type-C 单板供电时，5V 和 3.3V 同样明显异常。

## 2. 当前判断与安全边界

当前阻塞点是原 STM32 控制板板载 3.3V 供电故障，不再按“仅缺少烧录工具或 UART 配置”处理。

在替换板完成验收前：

1. 不向故障板外灌 3.3V；
2. 不继续 USART3 烧录；
3. 不恢复动力保险和运动测试；
4. 不声明故障板仍在运行任何固件。

## 3. 后续验收顺序与当前结果

替换板到位后的计划验收顺序为：

1. Type-C 单板供电下的 5V、3.3V 和 RESET；
2. 车载控制支路 5V 供电；
3. WCH-Link / CMSIS-DAP + OpenOCD 的 SWD 连接；
4. USART3 最小发送；
5. Orin NX 串口接收；
6. 编码器和后续底盘控制。

后续公开状态：替换板已完成供电、SWD、USART3、Orin NX 串口接收和四路编码器低功率手动计数基础验证。该结果关闭原 3.3V 故障造成的替换板验收阻塞，但不表示正式控制协议、动力测试或落地运动已经完成。

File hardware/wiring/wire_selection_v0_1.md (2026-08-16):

# Project0 上一平台实装线束与连接边界

> **历史记录**：本文线束适用于上一 STM32/JGB/WSDC 平台。H60 重建线束按 [当前接线基线](h60_power_estop_wiring_v0_1.md) 重新定额和验收。

## 1. 文件作用

> 文档状态：正式 / P2 当前实装线束事实源
> 最近更新：2026-06-18

本文档记录 Project0 当前实装线材、线径、端子、连接端点和仍待验证的线束边界。文件名保留 `v0_1` 以避免破坏既有引用，但正文已由 P1.3 采购口径升级为 P2 实装事实源。

本文档不是完整原理图，也不表示所有线束固定、通断、极性、温升和跌落后复验已经通过。具体现场故障、测量值和分阶段验证结果仍以 `hardware/wiring/` 下对应原始记录及 P2 验收清单为准。

## 2. 适用边界

1. 主电池为 3S 主电池。
2. 主输入保险首版按 25A ATO / ATC 保险丝边界处理。
3. 分路保险盒提供主开关后的正极分路和负极汇流。
4. 急停按钮只控制继电器线圈，不承载电机动力大电流。
5. ACS712-30A 电流检测模块串在继电器之后、电机驱动板之前的动力正极路径上。
6. 电压检测模块为并联采样，不串入主电源回路。
7. 电机动力线和编码器线优先保留电机原厂自带线；如需延长，按本文档补线。
8. Orin NX 与 STM32 UART 只连接 GND / TX / RX，不连接 5V。
9. UART 屏蔽裸线按单端接地处理，不作为 GND / TX / RX 三根芯线之一。

## 3. 当前线材规格

| 规格 | 用途 | 当前状态 |
|---|---|---|
| 12AWG 红 / 黑硅胶线 | 主电源入口、动力支路主干 | 已具备并用于当前实装；继电器座和 ACS712 附近存在 16AWG / 14AWG 实装偏差，见 5.3 节 |
| 14AWG 红 / 黑硅胶线 | Orin NX DC-DC 输入/输出、动力分线端子到两块电驱、两块电驱负极回汇流排 | 已具备并用于当前实装 |
| 18AWG 红 / 黑硅胶线 | Mid360 DC-DC 输入/输出、传感器/控制支路 DC-DC 输入 | 已具备并用于当前实装 |
| 22AWG 多色线 | 急停线圈控制、采样模块信号、STM32 到电驱控制、低压小信号、必要的短距离控制支路输出 | 已具备并用于当前实装 |
| 24AWG 三芯屏蔽软线 | Orin NX 与 STM32 UART 通信 | 已具备并完成物理接入；最小收发待替换 STM32 验收后验证 |
| 24AWG 四芯屏蔽软线 | 编码器延长线，可选 | 本轮未采购；后续按实物距离决定是否补买 |

## 4. 端子与接插件口径

| 连接对象 | 端子 / 接插件 | 说明 |
|---|---|---|
| 主电池 XT60、主输入保险、总开关、分路保险盒、继电器触点、ACS712 大电流端、电驱 P+ / P- | 与线径匹配的冷压端子、环形端子、叉形端子或接线端子 | 主电源入口和动力支路不得裸线缠绕；端子额定电流应不低于对应支路保险和线径能力 |
| 分路保险盒 M6 螺柱 | M6 环形冷压端子 | 主正极输入、负极汇流排和必要支路使用 |
| 主电源总开关 M8 螺柱 | M8 环形冷压端子 | 12AWG 线径匹配，不得裸线压接 |
| 电驱控制端、采样模块、STM32 小信号接口 | 2.54mm 杜邦端子 / 胶壳或等效端子线 | 需做防松固定，避免散插线被拉脱 |
| Orin NX <-> STM32 UART | 2.54mm 杜邦母头端子 + 3P 胶壳 | 三芯线，GND / TX / RX；TX/RX 交叉连接 |
| 编码器延长 | 4P 杜邦胶壳或后续按实物接口另选端接方案 | 每个电机至少 VCC / GND / A / B 四芯；线束应与电机动力线分开走线；JST-XH 2.54 本轮不采购 |

当前端子具备与使用状态：

| 项目 | 状态 | 说明 |
|---|---|---|
| M8 4 平方环形冷压端子 | 已具备并用于当前实装 | 用于主电源总开关 M8 螺柱 |
| M6 4 平方环形冷压端子 | 已具备并用于当前实装 | 用于分路保险盒、汇流排等较粗线径支路 |
| M6 2.5 平方环形冷压端子 | 已具备并用于当前实装 | 用于 14AWG 左右支路，跌落后仍需复查压接与锁紧 |
| M6 1 平方环形冷压端子 | 已具备 | 用于 18AWG 左右支路，按实际端子和压接效果使用 |
| 0.5-4 平方管型冷压端子套装 | 已具备并用于当前实装 | 用于接线端子压接，避免细股线散丝 |
| 一进二出大电流分线端子 | 已装车 / 待最终固定和复验 | 用于 ACS712 输出后分到两块电驱 |
| 2.54mm 杜邦母头端子 | 已具备并用于当前实装 | 用于 STM32、电驱控制端、采样模块和 UART |
| 2.54mm 杜邦胶壳 | 已具备并用于当前实装 | 包含 1P / 2P / 3P / 4P / 5P / 2x5P 等常用规格 |
| JST-XH 2.54 | 不采购 | 当前接口优先使用杜邦或设备自带接线方式；后续如实物强制需要再单独评估 |

当前线束工具状态：

| 工具 | 状态 | 说明 |
|---|---|---|
| 棘轮式冷压端子压线钳 | 已具备并使用 | 用于环形冷压端子等大电流端子 |
| 管型端子压线钳 | 已具备并使用 | 用于 0.5-4 平方管型端子 |
| 杜邦小端子压线钳 | 已具备并使用 | 用于 2.54mm 杜邦端子；不作为 JST-XH 采购依据 |
| 自动剥线钳 | 已具备并使用 | 用于不同线径剥线，避免伤线芯 |
| 斜口钳 / 尖嘴钳 | 已具备并使用 | 用于剪线、整理端子和线束细部装配 |

## 5. 模块间连接

### 5.1 主电源入口

| 起点 | 终点 | 线径 | 颜色 | 备注 |
|---|---|---|---|---|
| 主电池 XT60 正极 | 主输入保险座输入 | 12AWG | 红 | PWR-002 / PWR-006 |
| 主输入保险座输出 | 主电源总开关输入 | 12AWG | 红 | PWR-006 / PWR-003 |
| 主电源总开关输出 | 分路保险盒正极输入 | 12AWG | 红 | PWR-003 / WIRE-001 |
| 主电池 XT60 负极 | 负极汇流排 | 12AWG | 黑 | 不经过主电源总开关 |

### 5.2 动力支路、急停和电流检测

| 起点 | 终点 | 线径 | 颜色 | 备注 |
|---|---|---|---|---|
| 分路保险盒动力支路正极 | 急停继电器触点输入 | 12AWG | 红 | 动力支路大电流 |
| 急停继电器触点输出 | ACS712 大电流输入 | 12AWG | 红 | 继电器之后进入总电流检测 |
| ACS712 大电流输出 | 动力分线端子 | 12AWG | 红 | 后续一分二到两块电驱 |
| 动力分线端子 | 电驱 1 P+ | 14AWG | 红 | 分线端子额定电流需留余量 |
| 动力分线端子 | 电驱 2 P+ | 14AWG | 红 | 分线端子额定电流需留余量 |
| 负极汇流排 | 电驱 1 P- | 14AWG | 黑 | 与正极分支成对走线 |
| 负极汇流排 | 电驱 2 P- | 14AWG | 黑 | 与正极分支成对走线 |
| 电驱输出 | 电机动力线 | 原厂线 | 原厂颜色 | 如需延长，短距离可用 22AWG，保守用 20AWG；当前不新采购 20AWG |

### 5.3 急停线圈控制回路

| 起点 | 终点 | 线径 | 颜色 | 备注 |
|---|---|---|---|---|
| 控制支路 / 继电器线圈供电正极 | 急停按钮 NC 触点 | 22AWG | 现有多色线 | 急停按钮不承载电机动力大电流 |
| 急停按钮 NC 触点 | 继电器线圈正极 | 22AWG | 现有多色线 | 按下急停后线圈失电 |
| 继电器线圈负极 | 负极汇流排 / 控制地 | 22AWG | 现有多色线 | 需与系统低压侧共地 |

2026-06-16 当前实装补记：

| 区段 | 当前实装 | 说明 |
|---|---|---|
| 保险盒第 4 路到继电器 `30` 前 | 保险盒侧 `12AWG`，继电器座侧自带 `16AWG` | 通过接线端子过渡；后续需温升复查 |
| 继电器 `87` 到 ACS712 输入 | 继电器座自带 `16AWG` | 当前已完成基础上电验证；后续需温升复查 |
| ACS712 输出到动力分线端子 | `14AWG` | 因 ACS712 大电流端子无法可靠塞入 `12AWG`，当前采用短距离 `14AWG` |
| 动力分线端子到两块电驱 `P+` | `14AWG` | 当前基础验证通过 |
| 两块电驱 `P-` 到保险盒负极输出口 | `14AWG`，两个环形端子叠压同一路负极 | 当前已做拉力检查；长期使用前仍需复查锁紧、防松和温升 |
| 急停 NC 到继电器线圈 | `22AWG` + 继电器座自带 `16AWG` | 线圈电流小，当前口径可接受 |

### 5.4 计算支路

| 起点 | 终点 | 线径 | 颜色 | 备注 |
|---|---|---|---|---|
| 分路保险盒计算支路正极 | Orin NX DC-DC 输入正极 | 14AWG | 红 | 计算支路独立供电，不受急停切断 |
| 负极汇流排 | Orin NX DC-DC 输入负极 | 14AWG | 黑 | 与输入正极成对走线 |
| Orin NX DC-DC 输出正极 | Orin NX / C1902 DC5525 中心正 | 14AWG | 红 | 当前输出约 12V；跌落后复验前再次确认极性与防松 |
| Orin NX DC-DC 输出负极 | Orin NX / C1902 DC5525 外圈负 | 14AWG | 黑 | 上电前必须确认极性 |

### 5.5 Mid360 独立感知供电支路

| 起点 | 终点 | 线径 | 颜色 | 备注 |
|---|---|---|---|---|
| 分路保险盒 Mid360 支路正极 | Mid360 DC-DC 输入正极 | 18AWG | 红 | Mid360 独立 12V 支路 |
| 负极汇流排 | Mid360 DC-DC 输入负极 | 18AWG | 黑 | 与输入正极成对走线 |
| Mid360 DC-DC 输出正极 | Mid360 一分三线电源正极 | 18AWG | 红 | 按一分三线实物端接 |
| Mid360 DC-DC 输出负极 | Mid360 一分三线电源负极 | 18AWG | 黑 | 按一分三线实物端接 |
| Mid360 以太网端 | Orin NX / C1902 RJ45 | 原厂一分三线 / 短网线 | 不适用 | 跌落后需复验接口、链路、点云和 IMU |

### 5.6 传感器/控制支路

| 起点 | 终点 | 线径 | 颜色 | 备注 |
|---|---|---|---|---|
| 分路保险盒控制支路正极 | 5V DC-DC 输入正极 | 18AWG | 红 | 只服务 STM32、采样模块和小信号接口 |
| 负极汇流排 | 5V DC-DC 输入负极 | 18AWG | 黑 | 与输入正极成对走线 |
| 5V DC-DC 输出正极 | STM32 5V / 小信号供电分配 | 22AWG | 现有多色线 | 若实物接口需要更粗，可用 20AWG，但当前不单独采购 |
| 5V DC-DC 输出负极 | STM32 GND / 小信号地 | 22AWG | 现有多色线 | 与系统低压侧共地 |

### 5.7 采样和控制信号

| 起点 | 终点 | 线径 | 颜色 | 备注 |
|---|---|---|---|---|
| 主电源正负采样点 | 电压检测模块输入 | 22AWG | 现有多色线 | 并联采样，不串入主电源回路 |
| 电压检测模块 VCC / GND / OUT | STM32 | 22AWG | 现有多色线 | OUT 接 STM32 ADC，按后续分压/滤波方案执行 |
| ACS712 VCC / GND / OUT | STM32 | 22AWG | 现有多色线 | ACS712 大电流端和信号端分开理解；`S / OUT` 必须经分压滤波后接 STM32 `PA1`，详见 `hardware/wiring/acs712_current_sensing_wiring_v0_1.md` |
| STM32 PWM / INA / INB / GND | 两块电驱控制端 | 22AWG | 现有多色线 | 端子形式按电驱 CN1 和 STM32 排针确定 |
| 电机编码器 VCC / GND / A / B | STM32 编码器输入 | 原厂线 / 后续可选 24AWG 四芯屏蔽软线 | 原厂颜色 / 屏蔽线 | 本轮未采购四芯屏蔽线；若原厂线长度不足，再按实物长度补买 |

JGB-520 编码器线序按当前 BOM 与实物照片收束为：蓝色为编码器 `VCC / +5V`，黑色为编码器 `GND / 0V`，黄色为 `C1 / A`，绿色为 `C2 / B`；红色和白色为电机动力线，不接入 STM32 编码器输入。

四个电机编码器 A/B 信号线接入 STM32 的 P2 决定如下：

| 电机 | 黄色 `C1 / A` | 绿色 `C2 / B` | STM32 定时器资源 |
|---|---|---|---|
| 左前 `LF` | `PA8` | `PA9` | `TIM1_CH1 / TIM1_CH2` |
| 左后 `LR` | `PA6` | `PA7` | `TIM3_CH1 / TIM3_CH2` |
| 右前 `RF` | `PC6` | `PC7` | `TIM8_CH1 / TIM8_CH2` |
| 右后 `RR` | `PA15` | `PB3` | `TIM2_CH1 / TIM2_CH2` |

固件配置时 `PA15 / PB3` 需释放 JTAG 复用，仅保留 SWD 调试；编码器信号接入前应确认 A/B 输出电平不超过 STM32 输入允许范围。

当前 P2 电驱控制线实际接线、颜色分配、STM32 引脚分配和安全初始化验证结果见 `hardware/wiring/motor_driver_control_wiring_v0_1.md`。

ACS712-30A 电流采样分压滤波小板采用 `3 列 x 4 行` 洞洞板布局：A 列为 `S_IN`，B 列为 `ADC_NODE / PA1_OUT`，C 列为 `GND`；`12kΩ` 接 `A1-B1`，`22kΩ` 接 `B2-C2`，`104 / 0.1uF` 电容接 `B3-C3`，`A4 / B4 / C4` 分别作为 `S_IN / PA1_OUT / GND` 接口。

### 5.8 Orin NX 与 STM32 UART

| 起点 | 终点 | 线径 | 端子 | 备注 |
|---|---|---|---|---|
| Orin NX / C1902 GND | STM32 GND | 24AWG 三芯屏蔽软线 | 2.54mm 杜邦母头 3P 胶壳 | 必须共地 |
| Orin NX / C1902 TX | STM32 RX | 24AWG 三芯屏蔽软线 | 2.54mm 杜邦母头 3P 胶壳 | TX/RX 交叉 |
| Orin NX / C1902 RX | STM32 TX | 24AWG 三芯屏蔽软线 | 2.54mm 杜邦母头 3P 胶壳 | TX/RX 交叉 |

三芯屏蔽线的裸线为屏蔽线，不是第四根通信芯线。当前屏蔽线处理口径为单端接地：一端悬空并绝缘，另一端接系统 GND，可接 Orin NX DC-DC 输出负极或同系统地。不得把屏蔽线两端同时接地，也不得把 TX / RX 错接到 GND。

### 5.9 急停 NO 状态反馈

急停按钮 `NO` 只作为 STM32 状态反馈，不参与动力切断。

当前口径：

| 起点 | 终点 | 线径 | 备注 |
|---|---|---|---|
| STM32 急停状态输入 GPIO | 急停按钮 `NO` 一端 | 22AWG | GPIO 配置输入 + 内部上拉 |
| 急停按钮 `NO` 另一端 | 控制支路 DC-DC 负极 / STM32 GND | 22AWG | 按下急停后 GPIO 被拉低 |

注意：`NO` 不接 12V，不接保险盒正极，不接继电器 `85 / 86`。当前仍需最终确认实际接入的 STM32 GPIO 引脚并同步固件。

### 5.10 P2 当前上电调试记录入口

截至 2026-06-16，第二层电源、控制支路、急停继电器、动力支路和 USB / 调试器反供电现象的现场调试记录见：

```text
hardware/wiring/p2_power_estop_bringup_record_v0_1.md
```

## 6. 历史采购长度与当前余量口径

| 线材 | 采购长度 | 说明 |
|---|---:|---|
| 12AWG 红色硅胶线 | 2m | 主电源正极、动力主干、继电器与 ACS712 |
| 12AWG 黑色硅胶线 | 2m | 主输入负极、必要动力负极补线 |
| 14AWG 红色硅胶线 | 2m | Orin NX 供电正极、电驱 P+ 分支 |
| 14AWG 黑色硅胶线 | 2m | Orin NX 供电负极、电驱 P- 分支 |
| 18AWG 红色硅胶线 | 2m | Mid360 DC-DC、5V 控制支路 DC-DC 输入/输出正极 |
| 18AWG 黑色硅胶线 | 2m | Mid360 DC-DC、5V 控制支路 DC-DC 输入/输出负极 |
| 24AWG 三芯屏蔽软线 | 2m | Orin NX <-> STM32 UART |
| 24AWG 四芯屏蔽软线 | 本轮不采购 | 编码器延长线后续可选，按电机原厂线长度和实际走线距离决定 |

22AWG 多色线已有库存，本轮不重复采购。若后续压接失败、线束返工或实际走线距离超出预期，再按 P2 装配实际补购。

线束固定辅件、热缩管和标签材料已经具备，但当前整车仍未完成全部固定、防拉扯和线号标识。P2 接线优先对主电源入口、动力支路、DC-DC 输入输出、UART、ADC 采样、电驱控制和电机 / 编码器线束进行两端标识；不要求每一小段线都单独贴标签。

## 7. 装配验证要求

1. 上电前必须逐段检查极性、通断和短路。
2. 所有大电流端子必须做机械拉力检查，不得裸线缠绕或虚压。
3. 主输入、动力支路、Orin NX 支路、Mid360 支路和控制支路应分区走线并做线号标识。
4. 电机动力线与编码器 / UART / ADC 采样线避免长距离紧贴并行。
5. P2 首次上电后应检查主电源入口、保险座、继电器、ACS712、电驱输入端、DC-DC 输入输出端和端子处温升。
6. 如发现保险丝发热、端子发热、线材发软、压接松动、电压跌落或通信异常，应暂停测试并复核线径、端子和接线路径。

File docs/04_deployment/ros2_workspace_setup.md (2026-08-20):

# ROS2 工作区与基础环境搭建

> **当前补充**：工作区骨架继续沿用；底盘桥接目标已改为 H60。现有 STM32 相关桥接/测试只能作为历史参考，H60 协议与安全状态机尚未实现。

## P1.4-1 ROS2 Humble 基础环境记录

记录日期：2026-06-03

本节记录 Orin NX 在 P1.4 工程环境搭建阶段的 ROS2 Humble 基础安装与最小通信验证结果。完成范围是基础环境；FAST-LIO2、Nav2、Livox 驱动、RealSense 驱动、仿真环境和正式 ROS2 工作区功能包仍待后续实现。

### 1. 安装前状态

安装前已确认：

| 项目 | 当前记录 |
| --- | --- |
| 主机名 | `project0-orin-nx` |
| 系统版本 | Ubuntu 22.04.5 LTS / jammy |
| 架构 | `aarch64` / `arm64` |
| 远程访问 | SSH 可用，Orin NX 已可按 headless 模式使用 |
| locale | `LANG=zh_CN.UTF-8`，`LC_ALL` 为空 |
| apt 源 | Ubuntu ports 与 NVIDIA Jetson r36.4 源可正常更新 |

安装前 `sudo apt update` 正常完成，并提示仍有大量系统软件包可升级。当前记录不执行整机 `apt upgrade`，避免在 Jetson / L4T 镜像上引入无边界系统变化。

### 2. ROS2 apt 源配置

已安装基础工具并启用 `universe`：

```bash
sudo apt install software-properties-common curl -y
sudo add-apt-repository universe
sudo apt update
```

GitHub 连通性检查通过：

```bash
curl -I https://github.com
```

返回过 `HTTP/2 200`。

按 ROS2 官方推荐方式安装 `ros2-apt-source`：

```bash
export ROS_APT_SOURCE_VERSION=$(curl -s https://api.github.com/repos/ros-infrastructure/ros-apt-source/releases/latest | grep -F "tag_name" | awk -F'"' '{print $4}')
echo $ROS_APT_SOURCE_VERSION
curl -L -o /tmp/ros2-apt-source.deb "https://github.com/ros-infrastructure/ros-apt-source/releases/download/${ROS_APT_SOURCE_VERSION}/ros2-apt-source_${ROS_APT_SOURCE_VERSION}.$(. /etc/os-release && echo ${UBUNTU_CODENAME:-${VERSION_CODENAME}})_all.deb"
sudo dpkg -i /tmp/ros2-apt-source.deb
sudo apt update
```

本次记录中 `ROS_APT_SOURCE_VERSION` 为：

```text
1.2.0
```

`sudo apt update` 已成功拉取 `http://packages.ros.org/ros2/ubuntu jammy` 的 sources 与 `arm64` packages。

### 3. ROS2 Humble 基础安装

已安装 ROS2 Humble 基础版与开发工具：

```bash
sudo apt install ros-humble-ros-base ros-dev-tools -y
```

说明：

1. 当前选择 `ros-humble-ros-base`，不是 `ros-humble-desktop`。
2. 这是为了先建立轻量、可验证的 ROS2 基线。
3. RViz、Gazebo、Nav2、FAST-LIO2、Livox 驱动、RealSense 驱动等后续按阶段需要再补，不在本节写成已完成。

### 4. 基础验证

已执行：

```bash
source /opt/ros/humble/setup.bash
ros2 pkg list | head
printenv ROS_DISTRO
```

验证结果：

1. `ros2 pkg list` 可列出 ROS2 包，例如 `action_msgs`、`ament_cmake` 等。
2. `printenv ROS_DISTRO` 输出 `humble`。
3. `ros2 --version` 在 Humble 中不是有效参数；该命令显示 usage 和 `unrecognized arguments: --version` 不作为安装失败判断。
4. `ros2 pkg list | head` 出现过 `BrokenPipeError`，这是 `head` 提前关闭管道导致的输出中断，不作为 ROS2 安装失败判断。

已执行：

```bash
ros2 doctor --report
```

关键结果：

| 项目 | 当前记录 |
| --- | --- |
| ROS distribution | `humble` |
| Distribution type | `ros2` |
| Release platform | Ubuntu jammy |
| RMW middleware | `rmw_fastrtps_cpp` |
| 网络接口 | `lo`、`wlP1p1s0`、`enP8p1s0`、`l4tbr0`、`usb0`、`usb1` |
| 当前 Wi-Fi IPv4 | `<orin-nx-ip>` |

`ros2 doctor --report` 出现过 `Fail to call PackageReport class functions` warning。当前基础通信验证已通过，因此该 warning 先记录为待观察项，不作为 P1.4-1 阻断问题。

### 5. demo 节点安装与 talker/listener 验证

初次检查：

```bash
ros2 pkg list | grep demo_nodes
```

未发现 demo 包，因此已安装：

```bash
sudo apt install ros-humble-demo-nodes-cpp ros-humble-demo-nodes-py -y
```

安装内容包括：

1. `ros-humble-example-interfaces`
2. `ros-humble-demo-nodes-cpp`
3. `ros-humble-demo-nodes-py`

随后已完成 `demo_nodes_cpp` 的 talker/listener 最小通信测试。测试方式为两个 SSH 窗口分别运行：

```bash
source /opt/ros/humble/setup.bash
ros2 run demo_nodes_cpp talker
```

```bash
source /opt/ros/humble/setup.bash
ros2 run demo_nodes_cpp listener
```

用户确认测试成功。

### 6. shell 环境加载

talker/listener 测试成功后，已执行：

```bash
echo "source /opt/ros/humble/setup.bash" >> ~/.bashrc
source ~/.bashrc
printenv ROS_DISTRO
```

目的：让后续 SSH 登录后默认加载 ROS2 Humble 环境。

### 7. 当前结论

P1.4-1 ROS2 Humble 基础环境已完成最小验证：

1. ROS2 apt 源已添加；
2. `ros-humble-ros-base` 与 `ros-dev-tools` 已安装；
3. ROS2 Humble 环境变量可用；
4. `ros2 doctor --report` 可识别 Humble、平台和 RMW；
5. `demo_nodes_cpp` talker/listener 最小通信测试已成功；
6. Orin NX 可继续按 headless + SSH 方式推进后续环境搭建。

下一步建议进入 P1.4-2：ROS2 工作区骨架创建与 `colcon build` 验证。该步骤只应创建基础 workspace 和示例 / 空包，不提前展开正式控制、SLAM、导航或传感器驱动实现。

## P1.4-2 ROS2 工作区骨架创建与 colcon build 验证

记录日期：2026-06-03

本节记录 Orin NX 上 ROS2 工作区骨架创建、`colcon build`、工作区环境加载和最小包识别结果。工作区基础可用；正式控制、感知、SLAM、导航、传感器驱动和 launch 系统仍待后续实现。

### 1. 验证前状态

已通过 SSH 登录 Orin NX：

```bash
ssh user@<orin-nx-ip>
```

登录后确认 ROS2 Humble 环境变量已自动加载：

```bash
printenv ROS_DISTRO
```

输出：

```text
humble
```

曾直接执行：

```bash
/usr/bin/colcon
```

该命令输出 `usage` 并提示 `Error: No verb provided`。这是因为 `colcon` 需要指定 `build`、`list`、`test` 等 verb，不表示 `colcon` 不可用。

### 2. 创建空工作区并执行首次构建

已创建 ROS2 工作区目录：

```bash
mkdir -p ~/project0_ros2_ws/src
cd ~/project0_ros2_ws
```

随后在尚无 package 的工作区执行首次构建：

```bash
colcon build
```

输出：

```text
Summary: 0 packages finished [0.59s]
```

该结果说明空工作区可以被 `colcon build` 正常处理。

随后加载工作区环境：

```bash
source install/setup.bash
```

### 3. 创建最小 ROS2 包

创建最小 Python 类型 ROS2 package：

```bash
cd ~/project0_ros2_ws/src
ros2 pkg create p0_bringup --build-type ament_python
```

已创建：

1. `p0_bringup/package.xml`
2. `p0_bringup/setup.py`
3. `p0_bringup/setup.cfg`
4. `p0_bringup/p0_bringup/__init__.py`
5. `p0_bringup/resource/p0_bringup`
6. `p0_bringup/test/` 下的基础测试文件

创建时出现：

```text
[WARNING]: Unknown license 'TODO: License declaration'.
```

这是因为 `ros2 pkg create` 默认写入了占位 license，当前最小包仅用于工作区构建验证，后续正式保留或改造该包时再补充真实 license 信息。

过程中曾出现一次：

```text
-bash: cd: 参数太多
```

原因是多条命令被误粘贴到同一行，导致 `cd` 收到了多余参数。随后已分行重新执行正确命令，因此该错误不影响 P1.4-2 验证结论。

### 4. 构建最小包并验证 ROS2 可识别

回到工作区根目录：

```bash
cd ~/project0_ros2_ws
```

执行构建：

```bash
colcon build
```

输出：

```text
Starting >>> p0_bringup
Finished <<< p0_bringup [1.74s]

Summary: 1 package finished [2.24s]
```

构建后加载工作区环境：

```bash
source install/setup.bash
```

验证 ROS2 package 索引中可以识别 `p0_bringup`：

```bash
ros2 pkg list | grep p0_bringup
```

输出：

```text
p0_bringup
```

### 5. 当前结论

P1.4-2 ROS2 工作区骨架验证已完成：

1. Orin NX 上可创建 `~/project0_ros2_ws/src` 工作区；
2. 空工作区可执行 `colcon build`；
3. 工作区 `install/setup.bash` 可 source；
4. 可创建最小 `ament_python` 包 `p0_bringup`；
5. 包创建后可重新 `colcon build`；
6. source 工作区后，`ros2 pkg list` 可识别 `p0_bringup`。

该阶段完成工作区构建验证，正式功能代码尚未实现。后续如继续使用 `p0_bringup`，需要补充 package 元信息、license、维护者信息，并按正式包职责重新整理其内容。

## P1.4 仿真基础环境当前口径

记录日期：2026-06-04

当前 P1.4 最小收束没有安装或验证仿真环境，也没有创建 Gazebo world、URDF、仿真 launch 或仿真模型。

当前项目继续采用“真机主线，仿真辅助，真机验收”的口径：

1. 仿真基础环境不作为 P2 前置条件；
2. 如果硬件到货、装配、电气、STM32 下载 / 调试路径或 Orin NX 与 STM32 UART 等实体开发被阻塞，可将仿真作为并行替代工作；
3. 如果实体开发没有被阻塞，优先推进真机 P2；
4. 后续 P3 / P4 若需要降低 FAST-LIO2、Nav2 或运动控制链路的真机调试成本，可再按阶段需要补充仿真环境；
5. Gazebo、URDF、走廊简模、仿真 launch 和仿真验证当前均未完成。

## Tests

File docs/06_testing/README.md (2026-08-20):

# 测试与验收文档索引

## 1. 目录职责

`docs/06_testing/` 用于承载 Project0 的测试计划、验收清单、阶段门判定和测试结果索引。

本目录不替代：

1. 项目内部的 WBS、风险和事前规划；
2. `hardware/`、`firmware/`、`docs/04_deployment/` 中的原始实施与测试记录；
3. 内部变更执行记录；
4. 内部日常过程记录；
5. `reports/` 中面向总结和展示的正式报告。

## 2. 当前文件

| 文件 | 状态 | 职责 |
| --- | --- | --- |
| `p2_h60_mc520_rebuild_acceptance_plan_2026-08-16.md` | 当前执行入口 / H1 实物复核中，其余实物项 NOT RUN | H60 + MC520 新车 H0-H8 到货、CAD、三支路电气、固件、动力瞬态和落地准入 |
| `current_vehicle_h1_cad_review_2026-08-18.md` | 两轮数字审查完成 / H1 IN REVIEW | 保留第一轮问题并追加 2026-08-19 修正版 STEP 的拓扑、轴距/轮距、离地间隙、支柱、传感器姿态和加工状态复审 |

## 3. 当前 H60 与历史 STM32 记录

当前 H60 固件要求见 [`firmware/h60_motion_control_firmware_requirements_v0_2.md`](../../firmware/h60_motion_control_firmware_requirements_v0_2.md)。

以下记录包含上一 STM32 平台的临时固件行为、GPIO / 通道映射、工程与烧录信息、安全边界、诊断过程和测试结果，因此只读保留：

| 文件 | 内容 |
| --- | --- |
| [`firmware/stm32_safe_init_v0_1.md`](../../firmware/stm32_safe_init_v0_1.md) | 电驱控制端安全初始化固件与实测验证 |
| [`firmware/stm32_lf_single_motor_pulse_test_v0_1.md`](../../firmware/stm32_lf_single_motor_pulse_test_v0_1.md) | 左前单电机短脉冲测试 |
| [`firmware/stm32_four_single_motor_pulse_tests_v0_1.md`](../../firmware/stm32_four_single_motor_pulse_tests_v0_1.md) | 四个单电机短脉冲测试与通道映射 |
| [`firmware/stm32_suspended_linkage_pulse_tests_v0_1.md`](../../firmware/stm32_suspended_linkage_pulse_tests_v0_1.md) | 悬空同侧及四轮联动测试 |
| [`firmware/stm32_uart3_minimal_test_v0_1.md`](../../firmware/stm32_uart3_minimal_test_v0_1.md) | USART3 最小测试固件、双向 ACK 与重启 / 冷启动复验 |
| [`firmware/stm32_encoder_acceptance_v0_1.md`](../../firmware/stm32_encoder_acceptance_v0_1.md) | 旧平台新映射安全输出、四路编码器手动转轮和 `LF` 交叉故障定位 |

这些既有动力测试仅用于历史追溯，不能直接作为 H60 新平台接线或固件依据。

## 4. 使用规则

1. 阶段门记录形成后作为历史判定依据保留；如需纠正，应新增更正说明，不静默改写历史。
2. 执行中验收清单只把已经真实验证的事项写成完成。
3. 详细原始结果仍写入对应硬件、固件、部署或测试记录，验收清单只汇总判定和准入状态。
4. 后续新增阶段验收文件时，应区分“验收标准 / 执行清单 / 结果记录 / 阶段门记录”，避免一个文件同时承担全部职责。

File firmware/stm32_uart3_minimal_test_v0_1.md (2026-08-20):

# STM32 USART3 最小发送测试记录

## 1. 测试目标

该临时固件用于验证 STM32 USART3 到 Orin NX 的最小单向发送链路，不属于正式底盘控制固件。

计划行为：

1. 使用 USART3；
2. 波特率 `115200`；
3. 周期发送固定测试文本；
4. 电驱 PWM 保持为 `0`；
5. 不执行任何电机动作。

## 2. 接线边界

UART 只连接：

- STM32 TX → Orin NX RX；
- STM32 RX ← Orin NX TX；
- STM32 GND ↔ Orin NX GND。

UART 不连接 5V，TX / RX 必须交叉，双方使用 3.3V TTL 电平。

## 3. 当前状态

固件方案和串口参数已形成。原 STM32 控制板曾发生 3.3V 供电故障，因此当时暂停烧录和 Orin NX 收包验证。

后续替换板已完成供电、SWD、USART3 和 Orin NX 收包验证；Orin NX 可读取 STM32 周期输出，STM32 收到测试文本后可回传 ACK。

UART 物理链路和最小双向测试成立；正式控制协议、通信中断停车、无新指令停车和动力测试当时仍未完成。

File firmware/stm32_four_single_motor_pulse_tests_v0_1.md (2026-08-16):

# STM32 四电机单电机短脉冲测试固件记录 v0.1

## 1. 文件作用

本文档记录 Project0 P2 阶段 `LF / LR / RF / RR` 四个电机分别进行单电机低占空比短脉冲测试时的临时 STM32 固件行为、控制映射、诊断过程、主输入保险故障处理和最终测试结果。

本文档不是正式底盘控制固件设计，不包含闭环控制、编码器读取、UART 通信、ADC 采样、ROS2 通信、四轮联动控制或方向一致性定义。

## 2. 工程位置

本记录对应的 STM32CubeIDE 测试工程保存在本地开发环境中。该工程当前仍未纳入公开仓库源码管理，公开仓库只记录测试事实、关键配置和安全边界。

## 3. 测试目标

本阶段临时测试只回答一个问题：

```text
在受控条件下，STM32 能否分别通过两块电驱的四个通道让四个电机单独短时转动。
```

它不回答以下问题：

1. 四个电机正向是否一致；
2. 左右轮编码器符号是否一致；
3. 同侧双电机是否能同步；
4. 四轮是否能联动；
5. 整车落地后是否能直行或转向；
6. 急停链路是否已经有效；
7. 正式底盘控制固件是否完成。

## 4. 测试前提

| 项目 | 本次状态 |
|---|---|
| 测试策略 | 低占空比、短时间、一次只测一个电机 |
| 轮子状态 | 全部悬空 |
| 人工看守 | 有 |
| 安全默认 | `PWM=0, INA=H, INB=H`，电驱脱机 |
| 临时触发方式 | STM32 实体 `RESET` 后延时约 `5s`，只执行一次脉冲 |
| 脉冲参数 | `TIM4` 比较值 `8`，约 `14%` 到 `15%` 占空比，约 `500ms` |
| 急停机械安装 | 未完成 |
| 收尾要求 | 每轮临时测试后烧回安全初始化固件 |

## 5. 当前实测控制映射

左侧保持早期规划映射；右侧按最终实物走线便利性采用与早期规划相反的电驱通道映射。

| 电机 | 实际电驱 / 通道 | STM32 PWM | STM32 INA | STM32 INB | TIM4 通道 | 电机动力线 |
|---|---|---|---|---|---|---|
| `LF` 左前 | DRV-L `M1 / CH1` | `PB6` | `PD0` | `PD1` | `TIM4_CH1` | 红线 -> `M1A`，白线 -> `M1B` |
| `LR` 左后 | DRV-L `M2 / CH2` | `PB7` | `PD2` | `PD3` | `TIM4_CH2` | 红线 -> `M2A`，白线 -> `M2B` |
| `RF` 右前 | DRV-R `M2 / CH2` | `PB9` | `PD6` | `PD7` | `TIM4_CH4` | 红线 -> `M2A`，白线 -> `M2B` |
| `RR` 右后 | DRV-R `M1 / CH1` | `PB8` | `PD4` | `PD5` | `TIM4_CH3` | 红线 -> `M1A`，白线 -> `M1B` |

注意：

```text
右侧当前有效映射与早期文档假设不同：
早期假设：RF=M1，RR=M2
当前实物：RF=M2，RR=M1
```

后续正式底盘控制固件必须按当前实物映射实现，或在改线后同步更新本记录。

## 6. 临时测试固件通用行为

每次单电机测试只打开目标通道，其余通道保持 `PWM=0, INA=H, INB=H`。

通用伪代码：

```c
safe_offline_state();
HAL_Delay(5000);

target_INA = GPIO_PIN_RESET;
target_INB = GPIO_PIN_SET;

HAL_TIM_PWM_Start(&htim4, target_channel);
__HAL_TIM_SET_COMPARE(&htim4, target_channel, 8);
HAL_Delay(500);

__HAL_TIM_SET_COMPARE(&htim4, target_channel, 0);
safe_offline_state();
```

测试结束后，STM32 已烧回安全初始化固件。

## 7. 诊断过程摘要

### 7.1 左前 LF

`LF` 详见 `firmware/stm32_lf_single_motor_pulse_test_v0_1.md`。关键诊断为：

1. `PB6` 普通 GPIO 高电平 10s 诊断通过；
2. `TIM4_CH1 / PB6` PWM 诊断通过；
3. `LF / DRV-L / M1` 短脉冲转动通过。

### 7.2 左后 LR

`LR` 初次采用更保守参数 `compare=5`、约 `300ms` 未转动。后续执行：

1. 使用 `PB7` 普通 GPIO 高电平 10s 诊断，DRV-L `PWM2` 能稳定测得约 `3.3V`；
2. 恢复 `TIM4_CH2 / PB7`，采用 `compare=8`、约 `500ms`；
3. `LR / DRV-L / M2` 短脉冲转动通过。

### 7.3 右前 RF

`RF` 初次按早期假设使用 `DRV-R M1 / PB8 / PD4 / PD5` 测试未转动。后续发现实物接线为：

```text
RF 红线 -> DRV-R M2A
RF 白线 -> DRV-R M2B
```

因此将软件测试目标改为 `DRV-R M2 / PB9 / PD6 / PD7`。测试结果：

1. `PB8 -> DRV-R PWM1` 诊断曾通过，用于确认早期 M1 控制线；
2. 改按实际接线 `PB9 / PD6 / PD7` 后，`RF / DRV-R / M2` 短脉冲转动通过。

### 7.4 右后 RR

`RR` 实物接线为：

```text
RR 红线 -> DRV-R M1A
RR 白线 -> DRV-R M1B
```

测试过程：

1. 断电检查 DRV-R `M1A / M1B` 到 RR 电机线导通，现场确认正常；
2. 方向诊断固件保持 PWM=0，仅将 `PD4 / INA1` 拉低、`PD5 / INB1` 保持高电平；
3. 现场测得 `INA1` 低电平约 `0.18V`，可视为有效低电平，`INB1` 约 `3.3V`；
4. 恢复 `TIM4_CH3 / PB8` 短脉冲测试后，`RR / DRV-R / M1` 转动通过。

## 8. 主输入保险故障与处理

在 `LR` 测试准备过程中，现场听到疑似打火 / 噼啪声，随后发现左电驱动力上电异常。后续排查结果：

1. 电源开关输入端端子在移动第三层底板时松脱；
2. 主输入 25A ATO / ATC 保险丝熔断，保险丝本体测得 `OL`，内部熔断结构已断开；
3. 该现象与端子松动导致间歇接触、打火、瞬时过流高度吻合；
4. 现场更换电源开关输入端端子；
5. 现场更换同规格 25A ATO / ATC 主输入保险丝；
6. 断电通断检查、短时上电观察和左 / 右电驱动力输入检查恢复正常。

处理边界：

1. 不允许用导线短接保险丝；
2. 不允许为避免熔断而擅自换更大规格保险丝；
3. 该故障说明线束防拉扯、端子压接和层间移动余量仍需后续复查；
4. 该故障不改变 既有设计记录 的主输入保险选型结论。

## 9. 测试结果

| 电机 | 实际通道 | 结果 | 备注 |
|---|---|---|---|
| `LF` | DRV-L `M1 / CH1` | 通过 | 已在左前单电机测试记录中先行记录 |
| `LR` | DRV-L `M2 / CH2` | 通过 | 经 `PB7 / PWM2` 诊断后通过 |
| `RF` | DRV-R `M2 / CH2` | 通过 | 右侧按实物映射调整后通过 |
| `RR` | DRV-R `M1 / CH1` | 通过 | 经 M1 方向诊断后通过 |

阶段结论：

```text
四个电机均已完成单电机低占空比短脉冲动力测试。
每次测试均要求轮子悬空、人工看守、短时低占空比、一次只测一个电机。
测试后 STM32 已烧回安全初始化固件。
```

## 10. 边界和后续要求

已完成：

1. 电驱控制端安全初始化验证；
2. `LF / LR / RF / RR` 四个单电机短脉冲动力测试；
3. 右侧最终实物映射确认；
4. 主输入保险熔断故障定位与初步修复。

未完成：

1. 四轮方向一致性验证；
2. 编码器接线和读取；
3. 同侧双电机联动；
4. 四轮联动；
5. 整车落地低速运动；
6. 急停机械安装和继电器切断链路验证；
7. 线束最终固定、防拉扯、防振动整理；
8. 正式底盘控制固件。

后续要求：

1. 后续固件必须按当前实物映射处理右侧 `RF / RR`；
2. 正反转切换前仍必须先将 PWM 降为 `0%`；
3. 未完成急停链路前，不进行无人看守或落地动力测试；
4. 每次动力测试结束后仍应烧回安全初始化或确认正式固件默认安全态；
5. 在进入同侧双电机或四轮测试前，应先记录四个电机的实际转向。

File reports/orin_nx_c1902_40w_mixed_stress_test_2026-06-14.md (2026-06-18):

# Orin NX C1902 V1.1 40W 综合压力测试记录

## 1. 记录目的

本文记录 C1902 V1.1 载板更换后，Orin NX 16GB 在 `40W` 模式下进行 CPU + GPU + 内存综合压力测试的结果。

本次测试用于补充 C1902 载板的 `40W / MAXN SUPER` 稳定性验证，但只覆盖未接入相机、雷达、整车动力和真实 ROS2 业务负载时的计算侧压力测试，不替代后续装车联调、真实模型推理、传感器采集或长期运行验收。

## 2. 测试环境

| 项目 | 记录 |
| --- | --- |
| 测试日期 | 2026-06-14 |
| 主机名 | 已脱敏 |
| SSH 地址 | 已脱敏 |
| 计算模块 | Jetson Orin NX 16GB |
| 载板 | C1902 V1.1 Orin Nano / NX 系列载板 |
| 系统 | Ubuntu 22.04 / Jetson Linux R36.4 系列环境 |
| 内核 | `5.15.148-tegra` |
| 当前功耗模式 | `NV Power Mode: 40W` / mode `4` |
| 测试工具 | `stress-ng`、`nvcc`、CUDA 自定义 GPU 压力程序、`tegrastats` |
| 外设接入状态 | 相机、雷达、整车动力系统未接入 |
| 远程执行方式 | 通过同一局域网内的 SSH 远程执行 |

说明：本次远程测试时 `sudo` 仍需密码，因此未在脚本中重新执行 `sudo jetson_clocks`。测试开始时 `nvpmodel -q` 已确认设备处于 `40W` 模式。

## 3. 测试负载

综合负载由两部分同时运行：

1. CPU / 内存 / 矩阵压力：

```bash
stress-ng --cpu 4 --cpu-method matrixprod --vm 2 --vm-bytes 2G --matrix 2 --timeout 1200s --metrics-brief
```

2. CUDA GPU 压力程序：

```bash
./gpu_stress 1200
```

温度、频率和功耗记录：

```bash
tegrastats --interval 1000 --logfile tegrastats.log
```

脚本带有 `tj >= 85C` 自动停止保护。

## 4. 预检结果

先执行 3 分钟预检，结果如下：

| 指标 | 结果 |
| --- | --- |
| CPU 负载 | 8 核满载 |
| GPU 负载 | `GR3D_FREQ` 最高约 `99%` |
| 最高 `tj / cpu` | `77.5C` |
| 最高 GPU 温度 | `73.312C` |
| 最高输入功耗 | `25904mW`，约 `25.9W` |
| 结论 | 通过，可继续正式测试 |

## 5. 20 分钟正式测试结果

正式测试持续 20 分钟，结果如下：

| 指标 | 结果 |
| --- | --- |
| 测试目录 | `~/orionx_thermal_test/mixed_<timestamp>` |
| 持续时间 | `1200s` |
| CPU 压力程序退出状态 | `0` |
| GPU 压力程序退出状态 | `0` |
| CPU 负载 | 测试期间 8 核持续接近或达到满载 |
| GPU 负载 | 测试期间 `GR3D_FREQ` 基本维持 `99%`，结束阶段降为 `0%` |
| 最高 `tj / cpu` | `80.468C` |
| 最高 GPU 温度 | `76.25C` |
| 最高输入功耗 | `26068mW`，约 `26.1W` |
| Swap | 结束附近曾出现少量 Swap 使用，未导致测试失败 |
| 自动保护 | 未触发 `85C` 保护 |
| 稳定性现象 | 未观察到重启、SSH 断连、进程异常退出或测试卡死 |

`stress-ng` 结果摘要：

```text
stress-ng: info: successful run completed in 1200.12s (20 mins, 0.12 secs)
stress-ng: info: cpu      33179
stress-ng: info: vm    43825566
stress-ng: info: matrix 6344374
```

测试结束后远程复查：

```bash
pgrep -a stress-ng
pgrep -a gpu_stress
nvpmodel -q
```

其中 `stress-ng` 和 `gpu_stress` 无残留进程，`nvpmodel -q` 仍显示：

```text
NV Power Mode: 40W
4
```

## 6. 结论

在未接入相机、雷达和整车动力系统的条件下，C1902 V1.1 载板上的 Orin NX 16GB 已完成 `40W` 模式下 CPU + GPU + 内存综合压力测试。

本次结论：

1. 计算侧综合压力测试通过；
2. GPU 能够被 CUDA 压力程序拉到高负载，`GR3D_FREQ` 基本维持 `99%`；
3. CPU、GPU 和内存压力同时存在时，最高 `tj / cpu` 为 `80.468C`，未触发 `85C` 自动停止保护；
4. 最高输入功耗约 `26.1W`，说明该综合压力未吃满 `40W` 上限；
5. 当前结果支持继续推进后续真实业务负载测试和装车适配检查。

## 7. 边界与后续

本次测试不表示以下项目已经完成：

1. 相机实际采集链路；
2. Mid360 供电与数据链路；
3. Orin NX 与 STM32 UART 联调；
4. ROS2 人工接管逻辑；
5. 真实模型推理和传感器融合负载；
6. 整车装车后的长时间温升、线束、载板供电区域热点和机械固定验收；
7. 40W 上限被真实业务完整吃满时的长期稳定性。

后续建议：

1. 接入相机、雷达和必要供电支路后，进行真实业务负载 30 分钟以上测试；
2. 装车后重点复查载板 DC 输入口、电感、供电芯片、M.2 SSD 附近和线束弯折半径；
3. 若真实业务中 `tj / cpu` 长时间接近或超过 `85C`，应优先优化风道、散热器接触、风扇策略或功耗模式。

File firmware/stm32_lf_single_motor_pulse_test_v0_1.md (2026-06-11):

# STM32 左前单电机短脉冲测试固件记录 v0.1

## 1. 文件作用

本文档记录 Project0 P2 阶段左前 `LF` 单电机低占空比短脉冲测试所用的临时 STM32 固件行为、硬件接线、诊断过程和测试结果。

本文档不是正式底盘控制固件设计，不包含闭环控制、编码器读取、UART 通信、ADC 采样、ROS2 通信或四电机运动控制。

## 2. 工程位置

本记录对应的 STM32CubeIDE 测试工程保存在本地开发环境中。该工程当前仍未纳入公开仓库源码管理，公开仓库只记录测试事实、关键配置和安全边界。

## 3. 测试目标

本次临时测试只回答一个问题：

```text
在受控条件下，STM32 能否通过 DRV-L 的 M1 通道让左前 LF 电机短时转动。
```

它不回答以下问题：

1. 四个电机方向是否一致；
2. 左后、右前、右后电机是否可转；
3. 编码器是否能读取；
4. 整车落地后是否能直行；
5. 急停链路是否已经有效；
6. 正式底盘控制固件是否完成。

## 4. 测试前提

| 项目 | 本次状态 |
|---|---|
| 测试电机 | 左前 `LF` |
| 测试电驱 | DRV-L |
| 测试通道 | `M1 / CH1` |
| 轮子状态 | 悬空 |
| 人工看守 | 有 |
| 主电池输出 | 曾测得约 `10.88V` |
| 急停机械安装 | 未完成 |
| 测试策略 | 低占空比、短时间、单电机 |

## 5. 硬件连接

### 5.1 动力路径

| 环节 | 连接 |
|---|---|
| 电池正极 | 电池 XT60 输出正极 |
| 主输入保护 | 主输入保险丝 |
| 主开关 | 主电源开关 |
| 分路保险 | WIRE-001 多路保险盒 `MOT-L` 分路 |
| 电驱正极 | DRV-L `P+` |
| 电池负极 | 电池 XT60 输出负极 |
| 负极母排 | WIRE-001 多路保险盒负极母排 |
| 电驱负极 | DRV-L `P-` |

### 5.2 电机输出

| 电机线 | 电驱端子 |
|---|---|
| 左前电机红线 | DRV-L `M1A` |
| 左前电机白线 | DRV-L `M1B` |

### 5.3 控制线

| STM32 引脚 | 电驱端子 | 作用 |
|---|---|---|
| `PB6` | DRV-L `PWM1` | 左前 PWM |
| `PD0` | DRV-L `INA1` | 左前方向 A |
| `PD1` | DRV-L `INB1` | 左前方向 B |
| STM32 `3.3V` | DRV-L `VCC` | 电驱控制端逻辑供电 |
| STM32 `GND` | DRV-L `GND` | 控制地 |

## 6. 诊断过程

本次测试前曾出现 DRV-L `PWM1` 测点始终约 `0V` 的现象。后续按从简单到复杂的顺序排查：

1. 先把 `PB6` 临时配置为普通 GPIO 输出高电平，保持约 `10s`；
2. 现场确认 STM32 `PB6` 引脚侧电压正常；
3. 现场确认 DRV-L `PWM1` 端子侧电压正常；
4. 再把 `PB6` 配置回 `TIM4_CH1` PWM 输出；
5. 使用约 50% 占空比 PWM 诊断，现场确认 DRV-L `PWM1` 端子侧有正常输出；
6. 最后进入左前电机短脉冲测试。

结论：

```text
PB6 引脚、PB6 到 DRV-L PWM1 的控制线、TIM4_CH1 PWM 输出路径均已通过阶段诊断。
```

## 7. 临时测试固件行为

临时测试固件采用 `TIM4_CH1` 输出 `PB6` PWM。

关键行为：

1. 上电后先保持安全状态；
2. 延时约 `5s`，给现场操作者留出观察和断电准备时间；
3. 设置左前方向为 `INA=L, INB=H`；
4. 将 `TIM4_CH1` 比较值设为 `8`；
5. 当前 `TIM4` 周期参数下，对应约 `14%` 到 `15%` 占空比；
6. 保持约 `500ms`；
7. 将 PWM 重新设为 `0`；
8. 将方向恢复为 `INA=H, INB=H` 脱机；
9. 程序留在安全空循环中。

伪代码描述：

```c
safe_offline_state();
HAL_Delay(5000);

HAL_GPIO_WritePin(LF_INA_GPIO_Port, LF_INA_Pin, GPIO_PIN_RESET);
HAL_GPIO_WritePin(LF_INB_GPIO_Port, LF_INB_Pin, GPIO_PIN_SET);

HAL_TIM_PWM_Start(&htim4, TIM_CHANNEL_1);
__HAL_TIM_SET_COMPARE(&htim4, TIM_CHANNEL_1, 8);
HAL_Delay(500);

__HAL_TIM_SET_COMPARE(&htim4, TIM_CHANNEL_1, 0);
safe_offline_state();
```

## 8. 测试结果

| 项目 | 结果 |
|---|---|
| `PB6` GPIO 高电平诊断 | 通过 |
| `TIM4_CH1` PWM 诊断 | 通过 |
| 左前电机短脉冲转动 | 通过 |
| 重复稳定性 | 现场确认稳定 |
| 电机 / 电驱温度 | 现场确认无异常 |
| 异味 / 异响 | 现场确认无异常 |
| 本轮是否继续测其他电机 | 不继续 |

本次阶段结论：

```text
左前 LF / DRV-L / M1 单通道低占空比短脉冲动力测试通过。
```

## 9. 边界和后续要求

1. 本次只验证左前 `LF` 一条链路；
2. 左后 `LR`、右前 `RF`、右后 `RR` 未做动力测试；
3. 本次不冻结电机正反方向定义；
4. 编码器未读取；
5. 整车未落地运动；
6. 急停机械安装与急停链路仍未完成；
7. 临时测试固件不是常驻安全固件；
8. 本轮测试结束后，STM32 必须烧回安全初始化状态。

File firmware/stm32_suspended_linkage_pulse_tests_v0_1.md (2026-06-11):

# STM32 悬空同侧联动与四轮联动短脉冲测试记录 v0.1

## 1. 文件作用

本文档记录 Project0 P2 阶段在四个单电机低占空比短脉冲测试通过后，继续进行的悬空同侧双电机联动、四轮联动、方向一致性和相关诊断过程。

本文档不是正式底盘控制固件设计，不包含编码器读取、闭环调速、UART 通信、ADC 采样、ROS2 通信、急停闭环或整车落地运动控制。

## 2. 工程位置

本记录对应的 STM32CubeIDE 测试工程保存在本地开发环境中。该工程在本轮测试中被多次临时修改用于诊断和联动测试。测试结束后，工程最终已恢复并烧录回安全初始化行为：`PWM=0`，`INA=H`，`INB=H`。

## 3. 测试目标

本阶段临时测试回答以下问题：

1. 左侧 `LF + LR` 能否在悬空条件下短时同向起转；
2. 右侧 `RF + RR` 能否在悬空条件下短时同向起转；
3. 四个轮子能否在悬空条件下同时短时起转；
4. 在当前测试定义的“从车尾向车头看，朝车头方向为正方向”口径下，四轮方向能否通过软件补偿保持一致。

它不回答以下问题：

1. 编码器信号和符号是否正确；
2. 整车落地后是否能直行、转向或稳定停车；
3. 急停链路是否已切断动力；
4. 正式底盘控制固件是否完成。

## 4. 测试前提

| 项目 | 本次状态 |
|---|---|
| 测试策略 | 轮子悬空、人工看守、短时脉冲、先分侧再四轮 |
| 安全默认 | `PWM=0, INA=H, INB=H`，电驱脱机 |
| 临时触发方式 | STM32 实体 `RESET` 后延时约 `5s`，按固定顺序执行 |
| 初始联动参数 | `TIM4` 比较值 `8`，约 `14%` 到 `15%` 占空比，约 `500ms` |
| 诊断后联动参数 | `TIM4` 比较值 `20`，约 `36%` 占空比，约 `200ms` |
| 联动阶段间隔 | 约 `8s` |
| 急停机械安装 | 未完成 |
| 收尾要求 | 测试结束后烧回安全初始化固件 |

## 5. 当前实测控制映射与方向口径

### 5.1 通道映射

| 电机 | 实际电驱 / 通道 | STM32 PWM | STM32 INA | STM32 INB | TIM4 通道 |
|---|---|---|---|---|---|
| `LF` 左前 | DRV-L `M1 / CH1` | `PB6` | `PD0` | `PD1` | `TIM4_CH1` |
| `LR` 左后 | DRV-L `M2 / CH2` | `PB7` | `PD2` | `PD3` | `TIM4_CH2` |
| `RF` 右前 | DRV-R `M2 / CH2` | `PB9` | `PD6` | `PD7` | `TIM4_CH4` |
| `RR` 右后 | DRV-R `M1 / CH1` | `PB8` | `PD4` | `PD5` | `TIM4_CH3` |

### 5.2 方向定义

当前测试采用的方向定义为：

```text
从车尾向车头看，朝车头方向为正方向 / 向前。
```

按该定义，实测结果为：

1. 左侧在 `INA=L, INB=H` 时朝正方向；
2. 右侧在 `INA=L, INB=H` 时朝反方向；
3. 因此悬空联动测试固件对右侧采用软件反向补偿：`INA=H, INB=L`。

## 6. 初始联动测试与问题现象

在四个单电机测试通过后，曾先尝试把同侧联动和四轮联动直接建立在单电机阶段的保守参数之上：

| 参数 | 初值 |
|---|---|
| 比较值 | `8` |
| 占空比 | 约 `14%` 到 `15%` |
| 持续时间 | 约 `500ms` |

首次联动现象：

1. `LF` 在左侧联动阶段不转；
2. `LR` 可转；
3. 右侧两个轮子均可转，但方向与左侧相反；
4. 当时不能直接下结论说 `LF` 硬件损坏，因为其单电机测试此前通过。

## 7. LF 链路诊断过程

针对 `LF` 在联动时不转，依次执行了以下诊断：

### 7.1 动力链路复核

1. 左电驱 `P+ / P-` 供电复核通过；
2. 左侧支路保险导通正常；
3. `LF` 动力线、`DRV-L M1A / M1B` 通断检查正常；
4. 后续还发现保险盒正极输入端螺丝有松动并重新紧固，说明配电点仍需后续防松复查。

### 7.2 PWM 控制线诊断

仅保留 STM32 / 控制端上电，不接主动力，现场测得：

```text
DRV-L PWM1 在诊断窗口内约 3.26V
```

说明 `PB6 -> DRV-L PWM1` 控制线正常。

### 7.3 方向线诊断

仅保留 STM32 / 控制端上电，不接主动力，方向诊断固件保持：

```text
PWM = 0
LF_INA = L
LF_INB = H
```

现场确认：

1. `INA1` 低电平正常；
2. `INB1` 高电平正常。

说明 `PD0 / PD1 -> DRV-L INA1 / INB1` 方向线正常。

### 7.4 GPIO 直拉高绕过诊断

在接主动力、轮子悬空前提下，临时用 `PB6` 作为普通 GPIO 直拉高，绕过 `TIM4_CH1` 输出一个极短脉冲，`LF` 能动。

这一步说明：

1. `LF` 电机本体、左电驱 `M1` 功率通道和动力线可工作；
2. 不能简单写成 `LF` 硬件损坏。

### 7.5 TIM4_CH1 高占空比诊断

继续保持 `TIM4_CH1` 正常 PWM 路径，只把占空比提高到接近 `100%`，输出极短脉冲后，`LF` 同样能动。

阶段结论：

```text
LF 问题不是硬件损坏，也不是 TIM4_CH1 通道失效。
更符合“联动场景下，原 compare=8 的低占空比起转门槛不足”。
```

## 8. 最终联动测试固件行为

在完成上述诊断后，联动测试固件最终采用以下行为：

```c
safe_offline_state();
HAL_Delay(5000);

left_pair:   INA=L, INB=H, compare=20, pulse=200ms
HAL_Delay(8000);

right_pair:  INA=H, INB=L, compare=20, pulse=200ms
HAL_Delay(8000);

all_wheels:  left side INA=L/INB=H, right side INA=H/INB=L,
             compare=20, pulse=200ms

safe_offline_state();
```

说明：

1. `compare=20` 对 `Period=55` 约为 `36%` 占空比；
2. 右侧采用软件反向补偿，仅作为当前测试固件方向表；
3. 每轮测试完成后，固件仍回到 `PWM=0, INA=H, INB=H`。

## 9. 最终测试结果

### 9.1 同侧联动

| 阶段 | 结果 | 方向 |
|---|---|---|
| 左侧 `LF + LR` | 通过 | 均朝正方向 |
| 右侧 `RF + RR` | 通过 | 在软件反向补偿后均朝正方向 |

### 9.2 四轮联动

| 阶段 | 结果 | 方向 |
|---|---|---|
| `LF + LR + RF + RR` 同时短脉冲 | 通过 | 四轮均朝正方向 |

阶段结论：

```text
悬空条件下，同侧双电机联动和四轮联动均已通过。
按当前方向定义，右侧需要软件反向补偿后与左侧保持一致。
测试结束后，STM32 已烧回安全初始化固件。
```

## 10. 边界和后续要求

已完成：

1. 四个单电机短脉冲测试；
2. `LF` 低占空比起转门槛问题定位；
3. 悬空同侧双电机联动；
4. 悬空四轮联动；
5. 悬空方向一致性验证；
6. 测试后安全初始化回烧。

未完成：

1. 编码器接线和读取；
2. 线束最终固定、防松、防振、防拉扯整理；
3. 急停机械安装和急停继电器切断链路验证；
4. 整车落地低速运动；
5. 正式底盘控制固件。

后续要求：

1. 正式底盘控制固件必须显式记录当前方向表，不能默认左右同向参数完全相同；
2. 后续起步限幅和最低有效占空比应考虑 `LF` 的联动起转门槛，不能直接沿用 `compare=8`；
3. 未完成急停闭环前，不进入无人看守或整车落地动力测试；
4. 每轮动力测试结束后仍应烧回安全初始化或确认正式固件默认安全态。

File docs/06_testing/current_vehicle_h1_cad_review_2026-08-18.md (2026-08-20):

# 当前整车 H1 CAD 数字审查与复审记录

> 状态：`CONSISTENCY REVIEW COMPLETE / H1 IN REVIEW`
> 首轮日期：2026-08-18
> 复审日期：2026-08-19
> 口径统一：2026-08-20（当前 H60 硬件与运动约束边界）
> 依据：两轮数字 CAD 审查与 `p2_h60_mc520_rebuild_acceptance_plan_2026-08-16.md`
> 当前输入：`hardware/cad/current_vehicle_v0_2/step/` 中 28 个 STEP

## 1. 第一轮审查边界（历史快照）

本记录只回答当前 STEP 的单位、B-Rep 有效性、静态包络、关键尺寸、有限布尔相交、层间间隙和三视图可见布局。它不证明：

1. 实物尺寸、孔位、公差、材料、紧固、承载或加工可行性；
2. 线束、连接器、风道、插拔和拆卸空间已经完成；
3. 真实 Mid360 点云或 D435 RGB/深度视场无遮挡；
4. 急停、电源、接线、上电、固件或运动准入已经通过。

坐标口径：`x` 为前后方向，`y` 为竖直方向，`z` 为左右方向；第二层底板相对第一层底板上移 `73 mm`。

## 2. 几何健康

| 项目 | 结果 | 判定 |
| --- | --- | --- |
| STEP 数量与单位 | 27 个文件均声明 `SI_UNIT(.MILLI.,.METRE.)` | 通过 |
| B-Rep 有效文件 | 24 / 27 | 部分通过 |
| `Orin NX_MODEL.step` | 178 个 solid 中 4 个无效；15762 个 face 中 3 个无效 | 阻断 |
| Orin face 错误 | `InvalidImbricationOfWires` ×1；`UnorientableShape` ×2 | 阻断 |
| Orin 包围盒 | 常规算法异常扩展约 `200000 mm`；紧致包络约 `100.00 × 80.77 × 33.90 mm` | 阻断 |
| 第二层 / 整车装配 | 因包含无效 Orin 模型而同样无效 | 阻断 |
| 第一层装配 | 27 个 solid，B-Rep 有效 | 通过本项 |

无效 Orin 模型必须在 Fusion 或可信源模型中修复并重新导出；本轮没有修改 STEP，也没有把紧致包络计算解释为拓扑已修复。

## 3. 关键尺寸

| 项目 | 当前 STEP | 目标 / 边界 | 判定 |
| --- | ---: | ---: | --- |
| 轮心前后位置 | `x = ±85.00 mm` | 用户目标应形成 `180 mm` 轴距 | 阻断 |
| 轴距 | `170.00 mm` | `180.00 mm` | 少 `10.00 mm` |
| 轮心左右位置 | `z = ±92.08 mm` | 用户输入 `184.16 mm` 轮距 | 一致 |
| 轮距 | `184.16 mm` | `184.16 mm` | 通过本项 |
| 装配态轮胎包络 | 直径约 `66.35 mm`，宽约 `26.04 mm` | H0 到货实测后复核 | 待实物 |
| 左右轮胎最外侧 | 约 `210.20 mm` | 用户输入约 `210 mm` | CAD 多约 `0.20 mm`，待实物 |
| 第一层底板主体 | `290.00 × 189.40 mm`，主体厚 `3.00 mm` | 加工前复核孔位与局部台阶 | 未冻结 |
| 最低非轮结构离轮下沿 | 约 `9.18 mm` | 未定义通过阈值 | 阻断冻结 |
| 整车紧致外包络 | 约 `321.21 × 210.20 × 231.67 mm`（长 × 宽 × 高） | 不含线束、接头和实物公差 | 参考值 |

轴距修正建议只作为 CAD 动作输入：将前后两组轮心分别由 `x = ±85 mm` 调整到 `x = ±90 mm`，并同步检查电机支架孔位、第一层局部结构和轮胎包络。实际修改由用户在 Fusion 中完成，本记录不修改源模型。

## 4. 干涉与间隙

### 4.1 已执行的实体检查

- 第二层主开关向下穿过层板，其包围盒与右侧一个电机模块在层间重叠。
- 对主开关与四个电机模块分别执行实体布尔相交，四组相交体积均为 `0 mm³`；未发现开关本体与电机模块穿模。
- 三视图未见其他整件级明显穿模；该观察不替代全量装配干涉、螺纹啮合、公差和运动包络检查。

### 4.2 未关闭的空间边界

| 位置 | 静态间隙 / 现状 | 风险 |
| --- | ---: | --- |
| 电池顶面 -> 第二层板底 | 约 `11.00 mm` | XT60、绑带、出线、抽取方向和拆卸路径未建模 |
| H60 顶部 -> Orin 底部 | 约 `11.22 mm` | H60 插头、UART/调试、线束转弯和板卡维修空间未证明 |
| Orin 顶部 -> Mid360 平台底 | 约 `13.71 mm` | 风扇进风、热回流和维护空间未证明 |
| 电池 -> 前后电机模块包围盒 | 纵向最小约 `10.98 mm` | 电机/编码器线、应力释放和振动余量未建模 |
| 主开关本体 -> 电机模块 | 无实体穿模 | 端子、线耳、绝缘罩和电源线弯曲半径未建模 |

因此，本轮不能把“无明显本体穿模”写成线束、散热或维护通过。

## 5. 视场初审

### 5.1 Mid360

Livox 官方参数给出水平 `360°`、竖直 `-7°~52°`。当前 STEP 中 Mid360 位于整车最高处，三视图未见高于其扫描主体的其他整车部件；但模型没有官方 FOV 实体、精确光学原点和线缆，顶部平台及本体的近场自遮挡也未用点云验证。

判定：`ADVISORY / NOT PASSED`。后续导入 Livox 官方 FOV Model，或以真实点云检查 360° 水平遮挡和低仰角盲区。

官方依据：<https://www.livoxtech.com/cn/mid-360/specs>

### 5.2 D435

Intel 官方 D400 数据表给出 D435 深度 FOV：HD 约 `87° × 58°`，VGA 约 `75° × 62°`；RGB FOV 约 `69° × 42°`。当前 D435 本体前缘比第二层板前缘伸出约 `31.21 mm`，三视图未见车体实体位于镜头前方，但模型未包含精确光学原点、FOV 锥体、USB 插头和线缆。

判定：`ADVISORY / NOT PASSED`。后续以真实 RGB/深度流检查支架、车体边缘、线缆与近场盲区，并记录实际分辨率对应的 FOV。

官方依据：<https://www.intelrealsense.com/wp-content/uploads/2022/04/Intel-RealSense-D400-Series-Datasheet-April-2022.pdf>

## 6. 当时的硬件口径冲突（已关闭）

在 2026-08-18/19 数字审查时，STEP 不包含独立急停按钮和继电器，而当时的 BOM、接线基线、风险登记和 H1/H4 仍沿用旧链路，因此本节当时正确地标记为冲突。

2026-08-20 关闭结论：当前硬件口径已统一为“不设独立急停/继电器/急停 GPIO，只保留主保险、三支路保护、主开关人工断电、默认失能、显式 ARM、超时停车、IWDG、故障撤 PWM 与分阶段受监督测试”。这解决了文档与 CAD 的冲突，但不表示任何实物、上电或运动门已通过。

## 7. 第一轮 H1 判定（历史快照）

`H1 = IN REVIEW / BLOCKED`

至少需要以下闭环后才能复审：

1. 轴距从 `170 mm` 对齐到用户确认的 `180 mm`；
2. 修复 Orin 无效拓扑并重新导出第二层与整车总装；
3. 补齐连接器、线束、风道和拆卸包络；
4. 基于实物建立质量/重心表与最低离地间隙阈值；
5. 用官方 FOV 模型或真实数据关闭传感器遮挡；
6. 单独统一取消独立急停/继电器后的运动约束（已于 2026-08-20 完成数字口径统一）。

H1 未通过，H2-H8 不因本轮数字审查开放。

## 8. 第二轮数字复审（2026-08-19）

### 8.1 输入变化与用户最终口径

本地建模工作区更新后，当前输入为 28 个 STEP。相比第一轮，关键变化为：

1. 修复 Orin NX，并重新导出第二层装配和整车总装；
2. 用户明确最新整车尺寸取代旧的 `180 mm` 轴距目标，当前 `170 mm` 轴距为最终设计输入；
3. D435 由下俯 `5°` 改为与地面平行；
4. 两层底板增加前后中部支柱孔位，层间结构采用 6 根支柱；
5. 第一层底板原电机支架限位凸起因加工方不支持而删除；
6. 新增 `M2.5通孔尼龙螺柱15mm.step`；
7. 用户已委托加工方切割两层铝板，并打印 D435 支架和 Mid360 平台。制件当前处于委托状态，交付、质量和装车验收均待后续完成。

### 8.2 自动几何复审结果

复审使用 OCP 7.7.2 逐文件导入并执行 B-Rep 有效性检查，结果如下：

| 项目 | 复审结果 | 判定 |
| --- | --- | --- |
| STEP 数量 | 28 个，均为毫米单位 | 通过 |
| B-Rep 有效文件 | 28 / 28 | 通过 |
| `Orin NX_MODEL.step` | 174 个 solid、15241 个 face，全部有效；紧致包络约 `100.00 × 80.76 × 33.90 mm` | 通过本项 |
| 第一层底板 | 1 个 solid、84 个 face；`290 × 189.4 × 3 mm` | 通过本项 |
| 第一层装配 | 25 个 solid、13902 个 face；约 `290 × 210.2 × 83.67 mm` | 通过本项 |
| 第二层底板 | 1 个 solid、61 个 face；`290 × 189.4 × 3 mm` | 通过本项 |
| 第二层装配 | 835 个 solid、34617 个 face；约 `319.05 × 189.4 × 146.70 mm` | 通过本项 |
| 整车总装 | 860 个 solid、48519 个 face；紧致包络约 `319.05 × 210.20 × 210.07 mm`（长 × 宽 × 高） | 通过本项 |

第一层装配由第一轮的 27 个 solid 减为 25 个 solid，且第一层底板自身为单一实体，这与删除原先两个独立限位凸起一致。这里的“一致”是几何结构解释，不是加工尺寸验收。

### 8.3 尺寸、支柱和传感器姿态

1. 四轮中心保持 `x = ±85 mm`、`z ≈ ±92.08 mm`，因此轴距为 `170 mm`、轮距约 `184.16 mm`；两者现在均符合用户最新确认口径。
2. 轮胎最外侧约 `210.20 mm`。轮胎下沿约 `y = -13.739 mm`，第一层底板最低面约 `y = -3.064 mm`，静态最低非轮结构离地约 `10.67 mm`。
3. 两层底板均存在四角孔位及 `x = 0、z = ±81.5 mm` 的两个中部支柱孔位；第一层装配包含四角和前后中部共 6 根约 70 mm 高的层间支柱。
4. D435 模块安装姿态为水平，不再保留固定下俯 `5°`。该姿态符合用户最终选择；真实地面可见范围仍须在装车后以 RGB/深度流验证。
5. Mid360 位于整车最高处；数字模型没有发现新出现的整件级明显遮挡，但仍需实物点云验证低仰角与近场遮挡。

### 8.4 复审后 H1 判定

`H1 = IN REVIEW`

本轮已关闭第一轮的两项数字阻断：

1. `170 mm` 与 `180 mm` 的口径冲突已由用户最新决定关闭；
2. Orin、第二层装配和整车总装的无效 B-Rep 已修复。

仍未关闭：

1. 加工件尚未交付，材质、厚度、孔径/孔距、平面度、打印尺寸、打印方向和表面质量尚未实测；
2. 6 根层间支柱的实物装配一致性、紧固防松和整车扭转刚度尚未验证；
3. 连接器、线束弯曲、风道、拆卸路径、质量/重心和动态离地间隙尚未形成证据；
4. D435 与 Mid360 的真实数据遮挡测试尚未执行；
5. 当前无独立急停/继电器的运动约束已完成数字口径统一；但默认失能、显式 ARM、超时、IWDG、故障撤 PWM、主开关可达性与低能量分阶段测试都尚未以实物证据验收。

因此，“已委托加工”不能写成 H1 通过，也不能开放 H2-H8、上电或运动。收货后应先执行不上电的尺寸检查和试装复验。

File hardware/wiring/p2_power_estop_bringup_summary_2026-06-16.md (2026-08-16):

# P2 电源与急停上电验证摘要

> **历史记录**：本文是上一实车平台测试结果；新 H60 急停、电源和反供电必须按 H0-H8 重新验收。

## 1. 记录范围

本文记录 2026-06-16 完成的一轮 P2 电源分支、控制支路和急停动力切断验证。内容为公开技术摘要，不包含内部交接过程。

## 2. 已验证结果

1. 控制支路 DC-DC 输入端曾因剥线和压接接触不良导致输出链路为 `0V`；重新处理端子后，DC-DC 本体输出约 `5.12V`，STM32、ACS712 和编码器指示灯恢复。
2. 急停按钮使用 `NC` 触点控制继电器线圈。
3. 动力正极路径为：保险盒动力支路 → 继电器触点 → ACS712 → 动力分线端子 → 两块电机驱动器。
4. 急停未按下时，电驱 `P+ / P-` 可测得电池电压；按下急停后接近 `0V`。
5. 急停只切断动力支路，计算和控制支路不由急停直接断电。

## 3. USB 反供电现象

主电源关闭但 STM32 USB / 调试器仍连接时，电驱端曾测得约 `4.16V`，电驱指示灯仍可能点亮。拔掉 USB / 调试器后，电驱 `P+ / P-` 回到 `0V`。

当前边界：

1. 该现象按控制侧低电压反供电或残余供电处理，不作为继电器触点粘连的证据。
2. 判断整车动力是否真正断电，应同时关闭主电源并断开 STM32 USB / 调试器，再测量电驱输入。
3. 动力测试时优先使用车载控制支路给 STM32 供电。

## 4. 尚未完成

本次验证不表示线束最终固定、UART、编码器、ACS712 标定、长期温升或整车落地运动已经完成。

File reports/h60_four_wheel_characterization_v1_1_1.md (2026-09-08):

# H60 + MC520 四轮单轮运动表征报告（v1.1.1）

## 目的与范围

本报告汇总 Project0 在 P2 阶段取得的四轮单轮受限表征，用于冻结轮位与 H60 端口之间的物理方向、原始编码器符号、工程 CPR 和停车证据。测试均为单轮架空、短时、受控条件；没有执行四轮组合或落地运动。

后轮使用两根临时 `20 cm` 原厂线完成方向与 CPR 表征。该配置可以支持本报告的单轮结论，但不能替代最终长度线束、永久固定、应力释放或整车回归。

## 表征结果

| 轮位 / 端口 | plus 物理方向 / 净计数 | minus 物理方向 / 净计数 | 五圈样本 × 2 | 工程 CPR / 跨度 |
| --- | --- | --- | --- | --- |
| 右前 / MA | 向后 / `-175` | 向前 / `+193` | `+14611 / +14646` | `2926 / 0.2393%` |
| 左前 / MB | 向前 / `-113` | 向后 / `+211` | `-14614 / -14612` | `2923 / 0.0137%` |
| 右后 / MC | 向后 / `-37` | 向前 / `+225` | `+14626 / +14662` | `2929 / 0.2458%` |
| 左后 / MD | 向前 / `-138`，停位复样 `-112` | 向后 / `+114` | `-14618 / -14605` | `2922 / 0.0890%` |

左前 plus 的 `-113` 是成功样本；同一 `50‰` 请求曾有一次未起转且净计数为 `+1`，轮位调整后才取得成功结果。该失败被保留为起转可靠性与负载余量的限制。

## 方法与判据

- 方向样本只驱动一个 H60 端口，观察目标轮实际方向，同时检查目标口计数符号与非目标口是否保持不变。
- CPR 样本在零发送状态下手转目标轮五圈，每轮取两次样本；工程 CPR 由五圈净计数换算并取中值，再给出建议整数。
- 两次 CPR 的跨度按两次样本差异相对其中值计算；四轮结果均小于 `0.25%`。
- 受限停车证据包括主机 STOP/失能、末端零增量和实际停轮观察。它只覆盖相应单轮、短时架空条件。

## 可复用结论

- 端口和轮位的原始方向/符号关系可作为最终坐标归一化与参数集成的输入。
- 四个工程 CPR 建议值可作为最终配置复核的候选值：MA=`2926`、MB=`2923`、MC=`2929`、MD=`2922`。
- 已完成的单轮方向与 CPR 无需在相同配置下无意义重复；配置改变后仍需有针对性的回归。

## 未关闭项

- 最终长度线束、永久固定、应力释放与最终 H60 端口占用回归。
- 四轮架空前进/后退、统一 STOP、链路丢失和故障处置。
- 带载、低电量、热、长时、PWM/电流波形及最终参数集成。
- H2/H3/H5 总门仍为 PARTIAL，H6 尚未通过；不能从本报告推出 P2 完成或落地运动资格。

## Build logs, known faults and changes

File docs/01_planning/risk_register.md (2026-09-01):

# P2 H60 重建风险登记

> 状态：公开工程基线；风险关闭必须依赖到货、测量和测试证据。

| 风险 | 等级 | 当前缓解与关闭证据 |
| --- | --- | --- |
| H60/MC520 型号、针序或资料与目标不一致 | 高 | H0 核对丝印、接口、配件、R150、六芯线逐线通断和厂家资料 |
| AT8236 单路限流低于 MC520 堵转电流 | 高 | 低占空、单路到四路逐级测试，记录电流、压降和温升；堵转扭矩尚未验证 |
| 急停释放后意外恢复运动 | 高 | H60 冷启动为 `DISARMED/PWM=0`，清旧命令/PID；Orin 锁存急停并要求新会话显式 ARM |
| Orin 保活、H60 失电时 UART 反供电 | 高 | H4 测量掉电侧电源轨和引脚；使用掉电高阻缓冲/隔离后方可固定连接 |
| 继电器、保险、线材或端子额定不匹配 | 高 | 以线材/端子和实测电流确定保护值；验证继电器 DC 分断能力和内置二极管方向 |
| 动力回生/浪涌损伤 H60 或电源 | 高 | 示波器观察制动、反转、急停和主开关断开瞬态，再决定吸收措施 |
| Mid360 支路在低电量或动力瞬态下掉电 | 高 | 验证升降压输入下限、冷启动峰值、压降、温升和点云连续性 |
| H60 VIN ADC 被误当作持续电池监控 | 中 | 多点校准；明确 H60 失电时无遥测，首版接受该可观测性缺口 |
| Orin 急停 GPIO/GND 或 pinmux 选择错误 | 高 | 断电核对载板针脚和 pinmux；外置上拉与串联限流；NO 只接 3.3V 干接点 |
| 新 CAD 加工公差、重心或维护空间不足 | 高 | 28 个 STEP 已通过数字 B-Rep 复审；加工件尚未交付，收货后检查材质/厚度/孔位/平面度并试装，再关闭质量/重心、动态离地、线束弯曲和维护空间 |
| 将旧平台测试结论迁移到新平台 | 高 | 旧 STM32/JGB/WSDC/CAD 文档标记历史；新平台从 H0 重新验收 |
| Orin NX/C1902 当前不可用 | 高 | 电气异常后已送专业维修并保持隔离；维修结论前不再上电。维修返回后先完成独立电源、启动、网络和接口复验，再恢复 ROS2 与传感器链 |
| H60-only 临时模式被误当作完整整车能力 | 高 | 依次使用 M0-M4/G0 子门；保持默认失能、显式 ARM、超时/IWDG、故障撤 PWM、逐路架空和单独运动授权。临时结果不关闭 H4-H8 |
| 无 Orin 手柄接口尚未确认 | 高 | 既定 USB 接收器路径依赖 Orin；先确认 H60 可用接口、输入回中与失联停车，不假定 H60 具备 USB HID 主机能力 |

任何高风险项未关闭时，不得将数字基线解释为可上电、可落地运动或可无人运行。

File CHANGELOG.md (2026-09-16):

# Project0 版本记录

本文件是面向读者的版本索引。每个版本的完整发布说明位于 [`docs/releases/`](docs/releases/README.md)；逐次开发过程和原始试验记录不在这里重复展开。

## 版本口径

- 正式阶段版本固定映射：P0=`v0.1`、P1=`v0.2`、P2=`v1.1`、P3=`v1.2`、P4=`v1.3`、P5=`v1.4`、P6=`v1.5`、P7=`v2.1`、P8=`v2.2`、P9=`v2.3`、P10=`v2.4`。
- 阶段未完成但形成完整、可复现、对外有价值且验证通过的阶段性成果时，使用 `vX.Y.N`；`N` 是从 1 开始递增的阶段性成果序号。
- 普通开发进度不创建版本标签。
- 历史 `v1.1-dev.1`、`v1.1-dev.2` 原样保留；P2 在新规则下的阶段性成果版本从 `v1.1.1` 开始递增。
- 阶段是否完成只由阶段验收决定，不能由版本数字或局部结果外推。

## [Unreleased] — P2 / 下一候选 `v1.1.3`

- 最终上位机回归、H1/H2 最终配置复核及其余未闭环工作继续保留在 Unreleased；不追溯并入 `v1.1.2`。

## [v1.1.2] — 2026-09-16

- 冻结 H60-only 四轮架空前进、后退、STOP 与真实 USB-COM 断开后的定性停车证据。
- 同步默认关闭的四轮固定 profile、五秒 ARM 绝对上限候选、75 ms 命令租约及对应宿主/源码/构建门测试；默认构建继续保持 `MOTION=0 / CAL=0`。
- 新增 localhost-only 假串口安全控制台、中文状态面板、短租约、旧请求拒绝、断连停车和故障锁止测试。
- 完整说明：[`docs/releases/v1.1.2.md`](docs/releases/v1.1.2.md)；公开成果报告：[`reports/h60_no_orin_w2_m3_v1_1_2.md`](reports/h60_no_orin_w2_m3_v1_1_2.md)。
- P2 正式版本仍为 `v1.1`；本阶段性成果不表示阶段完成。

## [v1.1.1] — 2026-09-08

P2 首个阶段性成果版本，冻结四轮单轮运动方向、编码器符号、两次五圈工程 CPR 与受限停车证据。后轮证据使用临时 20 cm 原厂线；H2/H3/H5 保持 PARTIAL，H6 未通过，本版本不表示 P2 完成，也不授权四轮组合或落地运动。

- 完整说明：[`docs/releases/v1.1.1.md`](docs/releases/v1.1.1.md)
- 公开报告：[`reports/h60_four_wheel_characterization_v1_1_1.md`](reports/h60_four_wheel_characterization_v1_1_1.md)
- GitHub 标签：`v1.1.1`

## [v1.1-dev.2] — 2026-09-01

历史开发预发布，冻结 H0 基线与 H60 安全控制检查点；不代表 P2、基础运动或手柄控制验收完成。

- 完整说明：[`docs/releases/v1.1-dev.2.md`](docs/releases/v1.1-dev.2.md)
- GitHub 标签：`v1.1-dev.2`

## [v1.1-dev.1] — 2026-08-20

历史开发预发布，冻结 P2 H60 + MC520 重建的首个公开基线；不代表 P2 完成。

- 完整说明：[`docs/releases/v1.1-dev.1.md`](docs/releases/v1.1-dev.1.md)
- GitHub 标签：`v1.1-dev.1`

## [v0.2] — P1 completed 2026-06-11

P1 正式阶段版本：项目立项、需求、架构和 P2 前置规划形成可追溯基线。

## [v0.1] — P0 completed 2026-04-17

P0 正式阶段版本：项目目标、边界、阶段与初始仓库结构建立。

## 历史开发快照

以下条目是 P1 期间的开发快照，不按当前阶段性成果规则解释，也不等同于正式发布。逐项变化仍可通过 Git 历史追溯。

| 快照 | 日期 | 摘要 |
| --- | --- | --- |
| `0.2.11` | 2026-06-11 | P1 收尾与 P2 前置冻结 |
| `0.2.10` | 2026-06-04 | P1 一致性审查与 WBS 收敛 |
| `0.2.9` | 2026-06-04 | P2 输入补强与职责边界修正 |
| `0.2.8` | 2026-06-03 | 视觉、ROS 与接口说明补强 |
| `0.2.7` | 2026-05-20 | P1 评审整改与资料组织 |
| `0.2.6` | 2026-05-14 | 系统级材料与接口基线整理 |
| `0.2.5` | 2026-05-13 | 规划与架构内容扩展 |
| `0.2.4` | 2026-05-06 | 项目结构和文档体系迭代 |
| `0.2.3` | 2026-04-24 | P1 方案细化 |
| `0.2.2` | 2026-04-21 | 需求与架构补充 |
| `0.2.1` | 2026-04-20 | P1 初始规划更新 |
| `0.2.0` | 2026-04-17 | P0 完成后的 P1 开发起点 |
| `0.1.0` | 2026-04-17 | 初始项目快照 |

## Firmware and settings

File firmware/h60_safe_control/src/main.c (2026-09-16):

#include "p0_build_config.h"
#include "p0_control.h"
#include "p0_hw.h"
#include "p0_iwdg_diagnostic.h"
#include "p0_m2a_calibration.h"
#include "p0_motion.h"
#include "p0_motion_scheduler.h"
#include "p0_protocol.h"

#include <stdbool.h>
#include <stddef.h>
#include <stdint.h>

#define P0_TELEMETRY_PERIOD_MS UINT32_C(100)

static p0_control_t g_control;
static p0_parser_t g_parser;
static uint32_t g_telemetry_sequence;
static uint32_t g_boot_fault_code;
static p0_motion_controller_t g_motion;
static p0_motion_scheduler_t g_motion_scheduler;
static p0_m2a_calibration_t g_m2a_calibration;
static bool g_motion_fault;
#if P0_IWDG_DIAGNOSTIC_BUILD != 0
static p0_iwdg_diagnostic_t g_iwdg_diagnostic;
#endif
#if P0_M2A_SLOWDRIVE_BUILD != 0
static p0_m2a_slowdrive_t g_slow;
static bool check_uart_rx_fault(void);

static bool slow_apply(p0_slow_action_t action)
{
    if (action == P0_SLOW_OFF || action == P0_SLOW_REJECT) {
        p0_hw_motor_force_safe(0);
        return action != P0_SLOW_REJECT;
    }
    if (action == P0_SLOW_NONE) return true;
    return p0_hw_slow_commit(&g_slow, action, g_control.last_heartbeat_ms);
}
#endif

static void motion_force_zero(void *unused)
{
    (void)unused;
#if P0_M2A_SLOWDRIVE_BUILD != 0
    p0_hw_motor_force_safe(0);
    p0_slow_reset(&g_slow);
#endif
    p0_motion_reset(&g_motion);
    p0_motion_scheduler_reset(&g_motion_scheduler);
    p0_m2a_calibration_reset(&g_m2a_calibration);
    p0_hw_motor_force_safe(0);
}

static bool motion_prepare_arm(void *unused, uint32_t now_ms)
{
    (void)unused;
#if P0_M2A_SLOWDRIVE_BUILD != 0
    p0_slow_arm(&g_slow, now_ms, p0_hw_motor_stop_generation());
    return true;
#elif P0_M2A_RUNTIME_AVAILABLE
    return p0_m2a_calibration_arm(&g_m2a_calibration, now_ms);
#elif P0_MOTION_RUNTIME_AVAILABLE
    (void)now_ms;
    return true;
#else
    (void)now_ms;
    return false;
#endif
}

static bool motion_calibration_hold(
    void *unused,
    uint8_t channel,
    int8_t direction,
    uint16_t duty_permille,
    uint32_t now_ms)
{
    int16_t output_permille[4];

    (void)unused;
#if P0_M2A_SLOWDRIVE_BUILD != 0
    (void)output_permille;
    (void)now_ms;
    return slow_apply(p0_slow_hold(&g_slow, channel, direction, duty_permille,
        p0_hw_millis(), p0_hw_motor_stop_generation()));
#elif P0_M2A_RUNTIME_AVAILABLE
    if (!p0_m2a_calibration_hold(
            &g_m2a_calibration,
            channel,
            direction,
            duty_permille,
            now_ms,
            output_permille)) {
        p0_hw_motor_force_safe(0);
        return false;
    }
    if (direction == 0) {
        p0_hw_motor_force_safe(0);
    } else {
        p0_hw_motor_apply_pwm(0, output_permille);
    }
    return true;
#else
    (void)channel;
    (void)direction;
    (void)duty_permille;
    (void)now_ms;
    (void)output_permille;
    p0_hw_motor_force_safe(0);
    return false;
#endif
}

static bool motion_set_targets(void *unused, const int16_t target[4])
{
    (void)unused;
    if (!p0_motion_set_targets(&g_motion, target)) {
        p0_hw_motor_force_safe(0);
        return false;
    }
    return true;
}

static bool motion_configure(void)
{
    p0_motion_config_t config = {0};

    config.control_period_ms = P0_MOTION_CONTROL_PERIOD_MS;
    return p0_motion_init(&g_motion, &config);
}

static void motion_service(uint32_t now_ms)
{
#if (P0_MOTION_OUTPUT_COMPILED != 0) && \
    (P0_M2A_CALIBRATION_BUILD == 0)
    int32_t encoder_count[4];
    int16_t output_permille[4];
    p0_motion_schedule_result_t schedule_result;

    if (g_control.state != P0_STATE_ARMED) {
        p0_motion_scheduler_reset(&g_motion_scheduler);
        return;
    }
    schedule_result = p0_motion_scheduler_poll(&g_motion_scheduler, now_ms);
    if (schedule_result == P0_MOTION_SCHEDULE_WAIT) {
        return;
    }
    if (schedule_result == P0_MOTION_SCHEDULE_LATE) {
        p0_control_local_fault(&g_control, P0_FAULT_LOCAL);
        return;
    }
    p0_hw_encoder_read(encoder_count);
    if (!p0_motion_step(&g_motion, encoder_count, output_permille)) {
        p0_control_local_fault(&g_control, P0_FAULT_LOCAL);
        return;
    }
    if (schedule_result == P0_MOTION_SCHEDULE_PRIME) {
        p0_hw_motor_force_safe(0);
        return;
    }
    p0_hw_motor_apply_pwm(0, output_permille);
#else
    (void)now_ms;
#endif
}

static void calibration_service(uint32_t now_ms)
{
#if P0_M2A_SLOWDRIVE_BUILD != 0
    /* 候选提交前先消费接收错误、核对通信期限和上层状态。 */
    if (check_uart_rx_fault()) return;
    now_ms = p0_hw_millis();
    p0_control_tick(&g_control, now_ms);
    if (g_control.state != P0_STATE_ARMED || !g_control.session_valid) return;
    if (!slow_apply(p0_slow_service(&g_slow, now_ms,
                                   p0_hw_motor_stop_generation()))) {
        g_motion_fault = true;
    }
#elif P0_M2A_RUNTIME_AVAILABLE
    int16_t output_permille[4];
    p0_m2a_service_result_t result = p0_m2a_calibration_service(
        &g_m2a_calibration,
        now_ms,
        output_permille);

    if (result != P0_M2A_SERVICE_OK) {
        p0_hw_motor_force_safe(0);
        g_motion_fault = true;
    }
#else
    (void)now_ms;
#endif
}

static void send_packet(const p0_packet_t *packet)
{
    uint8_t frame[P0_PROTOCOL_MAX_FRAME];
    size_t length = p0_packet_encode(packet, frame, sizeof(frame));

    P0_HW_ASSERT(length != 0);
    p0_hw_uart_write(frame, length);
}

static bool check_uart_rx_fault(void)
{
    if (!p0_hw_uart_take_rx_fault()) {
        return false;
    }
    p0_parser_init(&g_parser);
    p0_control_protocol_fault(&g_control);
    return true;
}

static void service_safety(uint32_t now_ms)
{
    if (p0_hw_supervisor_tripped()) {
        p0_control_local_fault(&g_control, P0_FAULT_WATCHDOG_PRETRIP);
    }
    calibration_service(now_ms);
    if (g_motion_fault) {
        g_motion_fault = false;
        p0_control_local_fault(&g_control, P0_FAULT_LOCAL);
    }
    p0_control_tick(&g_control, now_ms);
}

static void send_command_status(
    const p0_packet_t *command,
    p0_status_t status)
{
    p0_packet_t response = {0};

    response.type = (status == P0_STATUS_OK) ? P0_MSG_ACK : P0_MSG_NACK;
    response.payload_length = UINT16_C(4);
    response.session_id = command->session_id;
    response.sequence = command->sequence;
    response.payload[0] = command->type;
    response.payload[1] = (uint8_t)status;
    response.payload[2] = (uint8_t)g_control.state;
    response.payload[3] = (uint8_t)g_control.fault;
    send_packet(&response);
}

static int16_t clamp_i16(int32_t value)
{
    if (value > INT16_MAX) {
        return INT16_MAX;
    }
    if (value < INT16_MIN) {
        return INT16_MIN;
    }
    return (int16_t)value;
}

static int32_t encoder_delta(uint8_t channel, int32_t now, int32_t before)
{
    if ((channel == UINT8_C(1)) || (channel == UINT8_C(3))) {
        return (int32_t)(int16_t)((uint16_t)now - (uint16_t)before);
    }
    return (int32_t)((uint32_t)now - (uint32_t)before);
}

static void send_telemetry(void)
{
    static int32_t previous_count[4];
    p0_packet_t packet = {0};
    int32_t count[4];
    uint16_t vin_raw = 0;
    uint16_t vin_nominal_mv = 0;
    uint8_t i;

    p0_hw_encoder_read(count);
    (void)p0_hw_vin_read(&vin_raw, &vin_nominal_mv);

    packet.type = P0_MSG_TELEMETRY;
    packet.payload_length = UINT16_C(40);
    packet.session_id = g_control.session_valid ? g_control.session_id : 0;
    packet.sequence = ++g_telemetry_sequence;
    packet.payload[0] = (uint8_t)g_control.state;
    packet.payload[1] = (uint8_t)g_control.fault;
    packet.payload[2] = g_control.motion_output_available ? UINT8_C(1) :
                                                            UINT8_C(0);
    packet.payload[3] = g_control.self_test_ok ? UINT8_C(1) : UINT8_C(0);

    for (i = 0; i < UINT8_C(4); ++i) {
        int32_t delta = encoder_delta(i, count[i], previous_count[i]);
        p0_write_u32_le(
            &packet.payload[4U + (size_t)i * 4U],
            (uint32_t)count[i]);
        p0_write_i16_le(
            &packet.payload[20U + (size_t)i * 2U],
            clamp_i16(delta));
        previous_count[i] = count[i];
    }

    p0_write_u16_le(&packet.payload[28], vin_raw);
    p0_write_u16_le(&packet.payload[30], vin_nominal_mv);
    packet.payload[32] = P0_FIRMWARE_VERSION_MAJOR;
    packet.payload[33] = P0_FIRMWARE_VERSION_MINOR;
    packet.payload[34] = P0_FIRMWARE_VERSION_PATCH;
    packet.payload[35] = P0_FIRMWARE_CAPABILITIES;
    p0_write_u32_le(&packet.payload[36], g_boot_fault_code);
    send_packet(&packet);
}

int main(void)
{
    p0_motor_ops_t motor_ops;
    uint32_t last_telemetry_ms;
    bool self_test_ok;
    uint16_t vin_raw;
    uint16_t vin_nominal_mv;
    bool motion_config_valid;

    p0_hw_early_safe_init();
    p0_hw_init();
    p0_parser_init(&g_parser);

    motion_config_valid = motion_configure();
    motor_ops.force_zero = motion_force_zero;
    motor_ops.prepare_arm = motion_prepare_arm;
    motor_ops.set_wheel_targets = motion_set_targets;
    motor_ops.calibration_hold = motion_calibration_hold;
    motor_ops.context = 0;
    p0_control_init(
        &g_control,
        motor_ops,
        ((P0_MOTION_RUNTIME_AVAILABLE && motion_config_valid) ||
         P0_M2A_RUNTIME_AVAILABLE));

    g_boot_fault_code = p0_hw_take_retained_fault();
    self_test_ok = p0_hw_vin_read(&vin_raw, &vin_nominal_mv);
    (void)vin_raw;
    (void)vin_nominal_mv;
    p0_control_finish_boot(&g_control, self_test_ok);
    if ((g_boot_fault_code != P0_HW_FAULT_NONE) &&
        (g_boot_fault_code != P0_HW_FAULT_IWDG_RESET)) {
        p0_control_local_fault(&g_control, P0_FAULT_LOCAL);
    }

    p0_hw_watchdog_start();
    last_telemetry_ms = p0_hw_millis();
#if P0_IWDG_DIAGNOSTIC_BUILD != 0
    p0_iwdg_diagnostic_init(
        &g_iwdg_diagnostic,
        g_boot_fault_code,
        last_telemetry_ms);
#endif

    for (;;) {
        uint8_t byte;
        uint8_t rx_budget = UINT8_C(64);
        uint32_t now_ms;

        p0_hw_main_alive();
        now_ms = p0_hw_millis();

        service_safety(now_ms);

        while (rx_budget != 0) {
            p0_packet_t packet;
            p0_parse_result_t result;

            if (check_uart_rx_fault() || !p0_hw_uart_read_byte(&byte)) {
                break;
            }
            result = p0_parser_feed(&g_parser, byte, &packet);
            --rx_budget;

            if (result == P0_PARSE_PACKET) {
                /* 缓冲命令也必须先执行当下的失联/租约/会话检查，
                   不能用一轮开始时的旧时间续租已经过期的输出。 */
                now_ms = p0_hw_millis();
                service_safety(now_ms);
                if (check_uart_rx_fault()) {
                    break;
                }
                p0_status_t status = p0_control_handle_packet(
                    &g_control,
                    &packet,
                    now_ms);
                send_command_status(&packet, status);
            } else if (result < 0) {
                p0_control_protocol_fault(&g_control);
            }
        }

        (void)check_uart_rx_fault();
        now_ms = p0_hw_millis();
        service_safety(now_ms);
        motion_service(now_ms);
        if ((uint32_t)(now_ms - last_telemetry_ms) >=
            P0_TELEMETRY_PERIOD_MS) {
            last_telemetry_ms = now_ms;
            send_telemetry();
        }
#if P0_IWDG_DIAGNOSTIC_BUILD != 0
        if (p0_iwdg_diagnostic_should_stall(&g_iwdg_diagnostic, now_ms)) {
            p0_hw_iwdg_diagnostic_stall();
        }
        if (p0_iwdg_diagnostic_should_trigger_exception(
                &g_iwdg_diagnostic, now_ms)) {
            p0_hw_exception_diagnostic_trigger();
        }
#endif
        p0_hw_watchdog_feed();
    }
}

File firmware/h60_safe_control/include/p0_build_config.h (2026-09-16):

#ifndef P0_BUILD_CONFIG_H
#define P0_BUILD_CONFIG_H

#include <stdint.h>

#ifndef P0_MOTION_OUTPUT_COMPILED
#define P0_MOTION_OUTPUT_COMPILED 0
#endif

#ifndef P0_OFFLINE_MOTION_AUDIT_BUILD
#define P0_OFFLINE_MOTION_AUDIT_BUILD 0
#endif

#ifndef P0_MOTION_CALIBRATION_VALID
#define P0_MOTION_CALIBRATION_VALID 0
#endif

#ifndef P0_M2A_CALIBRATION_BUILD
#define P0_M2A_CALIBRATION_BUILD 0
#endif

#ifndef P0_M2A_SLOWDRIVE_BUILD
#define P0_M2A_SLOWDRIVE_BUILD 0
#endif

#ifndef P0_H6_CHARACTERIZATION_BUILD
#define P0_H6_CHARACTERIZATION_BUILD 0
#endif

#ifndef P0_H6_EXTENDED_WINDOW_BUILD
#define P0_H6_EXTENDED_WINDOW_BUILD 0
#endif

#ifndef P0_W2_FOUR_WHEEL_PROFILE_BUILD
#define P0_W2_FOUR_WHEEL_PROFILE_BUILD 0
#endif

#ifndef P0_W2_FIVE_SECOND_LINK_LOSS_BUILD
#define P0_W2_FIVE_SECOND_LINK_LOSS_BUILD 0
#endif

#ifndef P0_IWDG_DIAGNOSTIC_BUILD
#define P0_IWDG_DIAGNOSTIC_BUILD 0
#endif

#if (P0_IWDG_DIAGNOSTIC_BUILD != 0) && \
    ((P0_IWDG_DIAGNOSTIC_BUILD != 1) || \
     (P0_MOTION_OUTPUT_COMPILED != 0) || \
     (P0_OFFLINE_MOTION_AUDIT_BUILD != 0) || \
     (P0_MOTION_CALIBRATION_VALID != 0) || \
     (P0_M2A_CALIBRATION_BUILD != 0) || \
     (P0_M2A_SLOWDRIVE_BUILD != 0) || \
     (P0_W2_FOUR_WHEEL_PROFILE_BUILD != 0) || \
     (P0_W2_FIVE_SECOND_LINK_LOSS_BUILD != 0) || \
     (P0_H6_EXTENDED_WINDOW_BUILD != 0))
#error "IWDG diagnostic requires a motion-locked isolated build"
#endif

#if (P0_M2A_SLOWDRIVE_BUILD != 0) && \
    ((P0_M2A_SLOWDRIVE_BUILD != 1) || (P0_M2A_CALIBRATION_BUILD != 1) || \
     (P0_MOTION_OUTPUT_COMPILED != 1) || (P0_OFFLINE_MOTION_AUDIT_BUILD != 0))
#error "Slowdrive requires the explicit isolated M2-A PWM build"
#endif

#if (P0_H6_CHARACTERIZATION_BUILD != 0) && \
    ((P0_H6_CHARACTERIZATION_BUILD != 1) || \
     (P0_M2A_SLOWDRIVE_BUILD != 1) || \
     (P0_M2A_CALIBRATION_BUILD != 1) || \
     (P0_MOTION_OUTPUT_COMPILED != 1) || \
     (P0_OFFLINE_MOTION_AUDIT_BUILD != 0) || \
     (P0_MOTION_CALIBRATION_VALID != 0) || \
     (P0_IWDG_DIAGNOSTIC_BUILD != 0))
#error "H6 characterization requires the isolated runtime-selected slowdrive build"
#endif

#if (P0_H6_EXTENDED_WINDOW_BUILD != 0) && \
    ((P0_H6_EXTENDED_WINDOW_BUILD != 1) || \
     (P0_H6_CHARACTERIZATION_BUILD != 1) || \
     (P0_W2_FOUR_WHEEL_PROFILE_BUILD != 0))
#error "H6 extended window requires the explicit H6 characterization build"
#endif

#if (P0_W2_FIVE_SECOND_LINK_LOSS_BUILD != 0) && \
    ((P0_W2_FIVE_SECOND_LINK_LOSS_BUILD != 1) || \
     (P0_W2_FOUR_WHEEL_PROFILE_BUILD != 1) || \
     (P0_H6_EXTENDED_WINDOW_BUILD != 0))
#error "W2 five-second link-loss candidate requires isolated W2 profile build"
#endif

#if (P0_W2_FOUR_WHEEL_PROFILE_BUILD != 0) && \
    ((P0_W2_FOUR_WHEEL_PROFILE_BUILD != 1) || \
     (P0_H6_CHARACTERIZATION_BUILD != 1) || \
     (P0_M2A_SLOWDRIVE_BUILD != 1) || \
     (P0_M2A_CALIBRATION_BUILD != 1) || \
     (P0_MOTION_OUTPUT_COMPILED != 1) || \
     (P0_OFFLINE_MOTION_AUDIT_BUILD != 0) || \
     (P0_MOTION_CALIBRATION_VALID != 0) || \
     (P0_IWDG_DIAGNOSTIC_BUILD != 0))
#error "W2 four-wheel profile requires the isolated default-off slowdrive build"
#endif

#if (P0_MOTION_OUTPUT_COMPILED != 0) && \
    (P0_OFFLINE_MOTION_AUDIT_BUILD == 0) && \
    (P0_M2A_CALIBRATION_BUILD == 0)
#error "Motion code requires the audit target or the explicit M2-A build"
#endif

#if (P0_OFFLINE_MOTION_AUDIT_BUILD != 0) && \
    (P0_M2A_CALIBRATION_BUILD != 0)
#error "Offline audit and M2-A calibration modes are mutually exclusive"
#endif

#if (P0_M2A_CALIBRATION_BUILD != 0) && \
    (P0_MOTION_OUTPUT_COMPILED == 0)
#error "M2-A calibration mode requires the guarded PWM implementation"
#endif

#if P0_MOTION_CALIBRATION_VALID != 0
#error "M1 has no frozen H60 channel, encoder or wheel calibration"
#endif

#define P0_MOTION_RUNTIME_AVAILABLE \
    ((P0_MOTION_OUTPUT_COMPILED != 0) && \
     (P0_MOTION_CALIBRATION_VALID != 0))

#define P0_M2A_RUNTIME_AVAILABLE \
    ((P0_MOTION_OUTPUT_COMPILED != 0) && \
     (P0_M2A_CALIBRATION_BUILD != 0) && \
     (P0_MOTION_CALIBRATION_VALID == 0))
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

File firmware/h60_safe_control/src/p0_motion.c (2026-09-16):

#include "p0_motion.h"

#include <limits.h>
#include <stddef.h>

static uint32_t magnitude_i32(int32_t value)
{
    return (value < 0) ? (uint32_t)(-(int64_t)value) : (uint32_t)value;
}

static int8_t sign_i32(int32_t value)
{
    if (value > 0) {
        return INT8_C(1);
    }
    if (value < 0) {
        return INT8_C(-1);
    }
    return INT8_C(0);
}

static int32_t clamp_i64_to_i32(int64_t value)
{
    if (value > INT32_MAX) {
        return INT32_MAX;
    }
    if (value < INT32_MIN) {
        return INT32_MIN;
    }
    return (int32_t)value;
}

static int32_t move_towards(int32_t value, int32_t target, int32_t step)
{
    if (value < target) {
        int64_t next = (int64_t)value + step;
        return (next > target) ? target : (int32_t)next;
    }
    if (value > target) {
        int64_t next = (int64_t)value - step;
        return (next < target) ? target : (int32_t)next;
    }
    return value;
}

static int32_t rate_step(uint16_t rate_mm_s2, uint32_t period_ms)
{
    uint32_t step = ((uint32_t)rate_mm_s2 * period_ms) / UINT32_C(1000);

    if ((step == 0) && (rate_mm_s2 != 0)) {
        step = 1;
    }
    return (int32_t)step;
}

static int32_t encoder_delta(uint8_t bits, int32_t now, int32_t before)
{
    uint64_t modulus = (bits == UINT8_C(16)) ?
                           (UINT64_C(1) << 16) :
                           (UINT64_C(1) << 32);
    uint64_t mask = modulus - UINT64_C(1);
    uint64_t delta = ((uint64_t)(uint32_t)now -
                      (uint64_t)(uint32_t)before) & mask;

    if (delta >= (modulus >> 1)) {
        return (int32_t)((int64_t)delta - (int64_t)modulus);
    }
    return (int32_t)delta;
}

static int32_t estimate_speed(
    const p0_motion_config_t *config,
    uint8_t channel,
    int32_t delta)
{
    int64_t numerator = (int64_t)delta *
                        (int64_t)config->wheel_circumference_mm[channel] *
                        INT64_C(1000) *
                        (int64_t)config->encoder_polarity[channel];
    int64_t denominator =
        (int64_t)config->encoder_counts_per_revolution[channel] *
        (int64_t)config->control_period_ms;

    return clamp_i64_to_i32(numerator / denominator);
}

bool p0_motion_config_is_valid(const p0_motion_config_t *config)
{
    uint8_t i;

    if ((config == NULL) ||
        (config->control_period_ms != P0_MOTION_CONTROL_PERIOD_MS) ||
        (config->maximum_target_mm_s == 0) ||
        (config->acceleration_mm_s2 == 0) ||
        (config->deceleration_mm_s2 == 0) ||
        (config->reversal_zero_hold_ms < config->control_period_ms) ||
        (config->maximum_output_permille == 0) ||
        (config->maximum_output_permille >
         (uint16_t)P0_MOTION_OUTPUT_PERMILLE_MAX) ||
        (config->kp_q10 < 0) ||
        (config->kp_q10 > INT32_C(1000000)) ||
        (config->ki_q10_per_s < 0) ||
        (config->ki_q10_per_s > INT32_C(1000000))) {
        return false;
    }

    for (i = 0; i < P0_MOTION_CHANNEL_COUNT; ++i) {
        if ((config->encoder_counts_per_revolution[i] == 0) ||
            (config->encoder_counts_per_revolution[i] >
             UINT32_C(100000000)) ||
            (config->maximum_encoder_delta_counts[i] == 0) ||
            ((config->encoder_counter_bits[i] == UINT8_C(16)) &&
             (config->maximum_encoder_delta_counts[i] > UINT32_C(32767))) ||
            ((config->encoder_counter_bits[i] == UINT8_C(32)) &&
             (config->maximum_encoder_delta_counts[i] >
              UINT32_C(2147483647))) ||
            (config->wheel_circumference_mm[i] == 0) ||
            (config->wheel_circumference_mm[i] > UINT32_C(100000)) ||
            ((config->encoder_counter_bits[i] != UINT8_C(16)) &&
             (config->encoder_counter_bits[i] != UINT8_C(32))) ||
            ((config->encoder_polarity[i] != INT8_C(1)) &&
             (config->encoder_polarity[i] != INT8_C(-1)))) {
            return false;
        }
    }
    return true;
}

void p0_motion_reset(p0_motion_controller_t *controller)
{
    uint8_t i;

    controller->encoder_ready = false;
    for (i = 0; i < P0_MOTION_CHANNEL_COUNT; ++i) {
        controller->previous_encoder_count[i] = 0;
        controller->requested_target_mm_s[i] = 0;
        controller->ramped_target_mm_s[i] = 0;
        controller->measured_speed_mm_s[i] = 0;
        controller->integrator_q10[i] = 0;
        controller->output_permille[i] = 0;
        controller->active_direction[i] = 0;
        controller->pending_direction[i] = 0;
        controller->zero_hold_elapsed_ms[i] = 0;
    }
}

bool p0_motion_init(
    p0_motion_controller_t *controller,
    const p0_motion_config_t *config)
{
    uint8_t i;

    if ((controller == NULL) || (config == NULL)) {
        return false;
    }
    controller->config = *config;
    controller->config_valid = p0_motion_config_is_valid(config);
    p0_motion_reset(controller);

    if (!controller->config_valid) {
        for (i = 0; i < P0_MOTION_CHANNEL_COUNT; ++i) {
            controller->config.encoder_counts_per_revolution[i] = 0;
        }
    }
    return controller->config_valid;
}

bool p0_motion_set_targets(
    p0_motion_controller_t *controller,
    const int16_t target_mm_s[4])
{
    uint8_t i;

    if (controller == NULL) {
        return false;
    }
    if ((target_mm_s == NULL) || !controller->config_valid) {
        p0_motion_reset(controller);
        return false;
    }
    for (i = 0; i < P0_MOTION_CHANNEL_COUNT; ++i) {
        int32_t target = target_mm_s[i];
        if (magnitude_i32(target) > controller->config.maximum_target_mm_s) {
            p0_motion_reset(controller);
            return false;
        }
    }
    for (i = 0; i < P0_MOTION_CHANNEL_COUNT; ++i) {
        controller->requested_target_mm_s[i] = target_mm_s[i];
    }
    return true;
}
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

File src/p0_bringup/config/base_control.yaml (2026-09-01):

p0_linux_joy:
  ros__parameters:
    vendor_id: "04b4"
    product_id: "2411"
    device_path: ""
    publish_period_sec: 0.05
    reconnect_period_sec: 1.0
    link_timeout_sec: 0.30

p0_base_bridge:
  ros__parameters:
    serial_device: /dev/ttyTHS1
    baud_rate: 115200
    command_timeout_sec: 0.20
    comm_timeout_sec: 0.35
    refresh_period_sec: 0.05
    heartbeat_period_sec: 0.10
    linear_deadband_mps: 0.01
    angular_deadband_radps: 0.02
    # Both switches remain false until H4/H5 and H6 acceptance close.
    motion_commands_enabled: false
    wheel_mapping_confirmed: false
    # Current CAD nominal only; H6 must replace/freeze the measured value.
    track_width_m: 0.18416
    # Zero is an additional hard block until H6 freezes a tested wheel limit.
    wheel_target_limit_mmps: 0
    channel_wheels: [unmapped_a, unmapped_b, unmapped_c, unmapped_d]
    channel_signs: [1, 1, 1, 1]

p0_safety_manager:
  ros__parameters:
    manual_timeout_sec: 0.25
    autonomy_timeout_sec: 0.25
    manual_release_hold_sec: 0.50
    autonomy_enabled: false
    publish_period_sec: 0.05

p0_manual_control:
  ros__parameters:
    # Flydigi Android mode mapping revalidated on Orin on 2026-07-17.
    mapping_confirmed: true
    linear_axis: 1
    angular_axis: 2
    deadman_button: 6
    linear_scale: -0.20
    angular_scale: -0.80
    deadzone: 0.10
    joy_timeout_sec: 0.25
    publish_period_sec: 0.05

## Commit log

2026-06-03 initial public project snapshot
    [chassis_layer1_assembly_check_v0_1.f3z, chassis_layer1_assembly_check_v0_1.step, chassis_layer1_assembly_check_v0_1.stl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]
2026-06-08 docs: sync V2 scope and C1902 carrier board
2026-07-13 docs(public): sync stm32 validation status
2026-08-18 feat(cad): publish current vehicle STEP set
    [D435.step, D435支架.step, M2.5通孔尼龙螺柱15mm.step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]
2026-08-18 docs(public): align current and historical repository state
    [chassis_layer1_assembly_check_v0_1.f3z, chassis_layer1_assembly_check_v0_1.step, chassis_layer1_assembly_check_v0_1.stl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]
2026-09-08 release(p2): publish v1.1.1 wheel characterization
